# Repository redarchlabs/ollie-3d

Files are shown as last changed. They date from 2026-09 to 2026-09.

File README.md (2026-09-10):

# Build a Reachy robot — start here

Six teams, six robots. Each team builds a complete **Reachy Mini–style robot**: a head that
nods, tilts and turns on six motors, two springy antennae, two arms, a body that turns on a
printed base, a phone for a face, and a Raspberry Pi for a brain. Then you make it yours: its
own name, its own voice, and if you like, its own head designed in Blender.

They are copies of **Ollie**. Everything in this book has been built and broken once already,
and the notes are what that taught.

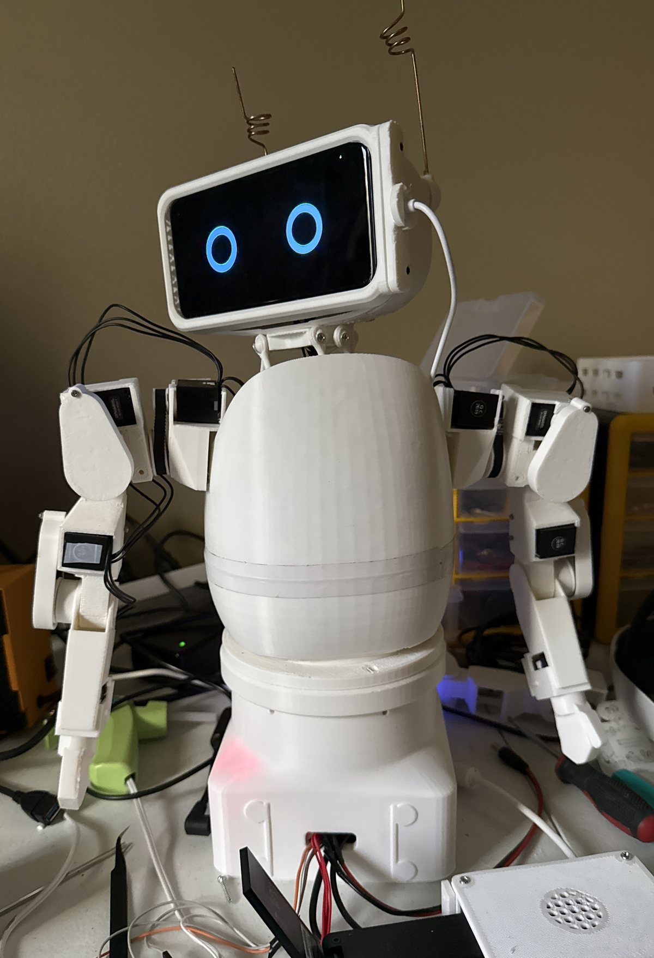
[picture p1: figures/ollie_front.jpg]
Ollie, the robot these are copies of


*Ollie: the phone face in the head, the wire antennae, both arms fixed to the top of the body,
the base that turns, and the Raspberry Pi in its white case beside the base.*

| Read this | When |
|---|---|
| **This page** | Day one: what you're building, the six stages, teams, safety |
| [Stage 1 — Print](1_PRINT.md) | Every printed part, test prints first |
| [Stage 2 — Motor IDs](2_MOTORS.md) | Set up the Pi, give all 17 motors their own ID |
| [Stage 3 — Assembly](3_ASSEMBLY.md) | Put the robot together, with the Pi beside you |
| [Stage 4 — Software](4_SOFTWARE.md) | Name, calibration, arms, autostart, the phone face |
| [Stage 5 — Testing](5_TESTING.md) | The acceptance test, the Code Lab (Blockly and JavaScript), VR control |
| [Stage 6 — Make it yours](6_CUSTOMIZE.md) | Optional: a different phone, voice and eyes, your own head in [Blender](BLENDER.md) |
| [Appendix A — Shopping list](PARTS.md) | What to buy, per robot and for six |
| [Appendix B — Mentor notes](MENTOR_SETUP.md) | Mentors: the kit, SD cards, the network, the power wiring |

---

## What you are building

| Part of the robot | What it is | Motors |
|---|---|---|
| **Head** | A 6-motor *Stewart platform*: six motor arms push six rods that hold up the head. Moving them together makes it nod, tilt, turn and bob | 6 × XL330-M288 (IDs 4–9) |
| **Antennae** | Two bent-wire antennae on the back of the head — the robot's main way to show emotion | 2 × XL330-M077 (IDs 1–2) |
| **Arms** | Two 4-joint printed arms driven by belts: shoulder pitch, shoulder roll, elbow, wrist | 8 × XL330-M288 (right 14–17, left 18–21) |
| **Body** | The "egg" that holds the head motors. The arms screw to the top of it | — |
| **Base** | A printed plinth with a bearing on top; the whole robot turns on it | 1 × XC330-M288 (ID 3) |
| **Face** | A Samsung Galaxy S10 behind the face plate. Its screen is the eyes, its speaker is the voice. A cable keeps it charged | — |
| **Brain** | A Raspberry Pi 5 beside the base. It runs the robot's software and talks to the motors through a USB adapter (the **U2D2**) | — |

**Seventeen motors on one cable.** Every motor is daisy-chained on a single bus, and every
motor has an ID number. The ID is how the software knows which motor is which, so setting the
IDs is the first thing you do with the motors (Stage 2).

**The Pi is your workbench computer.** From Stage 2 on, every command in this book is typed on
your robot's own Pi, with a monitor, keyboard and mouse plugged into it. You don't need a
laptop. The only other computer you'll use is for Blender, if you design a head in Stage 6.

### The six stages

| Stage | What | Who | You're done when |
|---|---|---|---|
| **1 · Print** | Test prints, then every part | Print lead | Every part is printed, checked and labelled |
| **2 · Motor IDs** | Set up the Pi; give each motor its ID | Motors lead + software lead + mentor | A scan finds all 17 motors |
| **3 · Assembly** | Head, antennae, face, arms, base, power | Mechanical lead + motors lead + mentor | The robot is built and its head's "level" is recorded |
| **4 · Software** | Name, calibration, arms, autostart, phone | Software lead + mentor | The robot starts by itself, calibrated |
| **5 · Testing** | Acceptance test, Code Lab, VR | Whole team | Every box on the checklist is ticked |
| **6 · Make it yours** | Optional: phone, voice, eyes, your own head | Designer + everyone | Whenever you like |

Every stage ends in a **✅ checkpoint**. Don't start the next stage until your robot passes it,
and don't start a stage at all until the pilot robot (R1) has passed it. Where a step says
**mentor**, a mentor is at the table for it.

---

## How six teams build six robots

**Every robot has a number, R1 to R6, for its whole life.** Put it on everything: printed parts
(pencil or marker on a hidden face), motors (painter's tape), cables, the SD card, the phone,
the USB stick, the parts bin. Six robots' worth of identical parts on one table is how a
calibrated part ends up in the wrong robot.

**R1 is the pilot robot.** One team runs each stage a few days ahead of everyone else. The other
five start a stage only after R1 has passed its checkpoint. A problem gets found once, not six
times. The same goes for printing: print one of anything new, check it, then print five more.

**Parts that belong to one robot never move to another.** Motors (their IDs and positions are
recorded), rods, motor arms, the calibration file and the phone all get matched to one robot.
Swapping a calibrated part is how the robot on the next table starts moving wrong.

### Roles on a team (4–5 people)

| Role | Owns |
|---|---|
| **Print lead** | The team's print queue, slicer settings, labelling printed parts |
| **Motors & wiring lead** | Motor IDs, cables, the bus, strain relief, the power checks |
| **Mechanical lead** | Rods, motor arms, the head and neck, the arms and belts, the base |
| **Software lead** | The Pi, the phone, the robot's name and voice (with the mentor) |
| **Designer** | Optional: the robot's own head in Blender (everyone can help) |

Everyone owns safety.

---

## Safety — non-negotiable

1. **The motors are 5-volt parts.** The robot's power brick is 12 V, and a converter turns that
   into 5 V for the motors. 12 V on the motor bus destroys **every motor at once**. Only a
   mentor wires or changes the power parts, and the 5 V is measured with a meter before any
   motor is connected.
2. **Power off before you plug or unplug any motor cable.** Hot-plugging is how a motor gets a
   wrong ID or drops off the bus.
3. **Keep fingers out of the neck and the belts while the motors are powered.** Six motor arms
   and six rods make a pinch point, and so does every belt. Before you move the head or an arm
   by hand, it must be *limp* (torque off).
4. **An arm falls when it goes limp.** Hold it, or make sure nothing is under it, before you
   switch the motors off or press PANIC.
5. **Soldering only with a mentor present.** Eye protection, ventilation, iron in its stand.
6. **Hot water for the ball joints (80–90 °C)** — tongs or gloves, mentor present.
7. **Phones:** never put a phone with a swollen battery into the head. The phone charges inside
   the head, so check its back is still flat every time the head is opened.
8. **Printers:** don't touch the nozzle or the bed. PETG needs ventilation.
9. **VR:** the person in the headset can't see the real robot. Someone else always watches the
   robot, with a hand near the power switch.
10. **Children will touch this robot.** Nothing sharp: round every point and edge, including
    the ends of the antenna wire.

---

## Day one

1. **Form six teams**, give each a robot number (R1 = the pilot team) and assign roles.
2. **Safety briefing** — the list above, out loud.
3. **Start printing the test pieces** ([Stage 1](1_PRINT.md)). They answer "will it fit?"
   before anyone commits a ten-hour print. Also start the long, safe prints: `body_top`,
   `body_down`, `head_back`, `base_body`.
4. **Inventory what has arrived** against the [shopping list](PARTS.md). Label boxes R1–R6.
5. **Software leads:** set up your Pi ([Stage 2, step 1](2_MOTORS.md)). It can happen while the
   printers run.
6. **Designers:** if your team wants its own head, install Blender and sketch the character on
   paper first ([Blender](BLENDER.md)). Design runs alongside the build.

## Where the files are

Everything to print, and this book, is in the **ollie-3d** repository. Your team also gets a
**USB stick** from the mentor with the same files plus the robot software:

| Folder | What's in it | Where |
|---|---|---|
| `print/` | Every part for one robot, grouped in printing order. **All millimetres — print at 100 %.** `PRINT_LIST.csv` says how many of each and how to lay it on the bed | ollie-3d and the USB stick |
| `blender/` | The Blender starter file and its check script (Stage 6) | ollie-3d and the USB stick |
| `Reachy-Student-Build-Book.pdf` | This book, ready to print | ollie-3d and the USB stick |
| `software/` | `reachy-software.tar.gz` — the robot software, installed onto the Pi in Stage 2 | USB stick only |

Keep the stick: it's also where your robot's calibration file is backed up.

**Credits.** The stock Reachy Mini parts — the head back, crown cover, neck and Stewart
plates, antenna parts and body shells — are Pollen Robotics' designs, converted here to
millimetres. Everything else was designed for Ollie.

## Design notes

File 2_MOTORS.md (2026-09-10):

# Stage 2 — Motor IDs

Every DYNAMIXEL motor leaves the factory as **ID 1 at 57600 baud**. Seventeen motors all
answering to "1" on one cable just talk over each other, so each motor gets its own ID
**before** they are chained together — one motor at a time, with nothing mechanical attached.
The tool that does it runs on your robot's Pi, so the Pi is set up first.

---

## 1. Set up the Pi — your workbench computer

*Software lead, with the mentor. This can happen on day one while Stage 1 prints.*

You need: the Raspberry Pi 5 and its **official 27 W power supply**, the Active Cooler, the SD
card the mentor prepared for your robot, a monitor and a micro-HDMI cable, a USB keyboard and
mouse, your team's USB stick, and the school wifi (the install downloads packages).

1. Press the **Active Cooler** onto the Pi (its two push-pins go into the holes beside the
   processor) and plug its fan lead into the socket marked FAN.
2. SD card in, then monitor (the HDMI port nearest the power socket), keyboard and mouse, and
   power last. The Pi starts to the desktop.
3. Connect to the wifi from the network icon at the top right, if the mentor hasn't already.
4. Plug in the USB stick. In the file manager, copy `software/reachy-software.tar.gz` from the
   stick into your **home folder**.
5. Open a **Terminal** (the black icon on the top bar) and install the software:
   ```bash
   tar -xzf reachy-software.tar.gz
   cd ~/reachy
   bash scripts/provision_pi.sh
   ```
   It takes several minutes and ends with **Done**. It installs the robot software, the motor
   tools, and the permission to use the motor adapter.
6. **Restart the Pi** (`sudo reboot`). That permission only takes effect after a restart.

**From here on, every command in this book is typed in a Terminal on the Pi, starting in the
`reachy` folder.** A new Terminal starts in your home folder, so type `cd ~/reachy` first.

---

## 2. Motor power on the bench (mentor)

The motors take **5 V** from the **U2D2 Power Hub**. On this robot the Power Hub is fed by a
converter that turns the 12 V power brick into 5 V ([Appendix B](MENTOR_SETUP.md) says how the
mentor wires it).

1. **Mentor:** with no motor plugged in, switch on and measure the Power Hub's input with a meter.
   It must read **about 5.0 V** (4.9–5.1). If it reads 12, stop: something is wired wrong, and 12 V
   destroys every motor it reaches.
2. Switch the Power Hub **off**. Plug the U2D2 into one of the Pi's USB ports, and connect the
   U2D2 to the Power Hub with the short 3-pin cable.

---

## 3. The ID map — the same on every robot

| ID | Motor | Model number the scripts print | Where it goes |
|---:|---|---:|---|
| 1 | XL330-**M077** | 1190 | Left antenna (the robot's own left) |
| 2 | XL330-**M077** | 1190 | Right antenna |
| 3 | **XC330**-M288 (metal case) | 1240 | Body turn, in the base |
| 4–9 | XL330-**M288** | 1200 | The six head motors |
| 14 | XL330-M288 | 1200 | **Right** arm — shoulder pitch (in the shoulder housing) |
| 15 | XL330-M288 | 1200 | **Right** arm — shoulder roll (on the fork, above the shoulder) |
| 16 | XL330-M288 | 1200 | **Right** arm — elbow (lying flat in the upper arm) |
| 17 | XL330-M288 | 1200 | **Right** arm — wrist (in the forearm) |
| 18–21 | XL330-M288 | 1200 | **Left** arm — the same order: pitch, roll, elbow, wrist |

All seventeen run at **1 Mbps** (1 000 000 baud). IDs 10–13 are not used. The software expects
exactly this map.

**The arm order matters.** The software reads the first ID of each arm as the shoulder pitch,
the next as the roll, and so on. On Ollie two shoulder motors went in the wrong places, and the
pitch slider moved the roll joint. Labelling every motor with its job now is what prevents that.

The head and the arms use the **same** motor, the XL330-M288. The two antenna motors (M077) look
identical but are weaker and faster, and the body-turn motor is the one with the metal case.
Check the model number the script prints every time.

---

## 4. Give each motor its ID

1. **Power Hub off.** Plug **one** motor into the Power Hub. Switch on — the motor's LED
   blinks once.
2. Give it its ID and the fast baud rate. For a head motor that will be ID 4:
   ```bash
   cd ~/reachy
   .venv/bin/python scripts/set_id.py --new-id 4 --new-baud 1000000
   ```
   The script refuses if it sees more than one motor, which is the point. It prints the motor's
   model number — check it against the table.
3. **Power off.** Stick a tape label on the motor with robot, ID and job: `R3 · 4 · head`,
   `R3 · 14 · R shoulder pitch`, `R3 · 21 · L wrist`. Unplug it.
4. Repeat for all seventeen: the two **M077** motors (1190) get IDs 1 and 2, the **XC330**
   (1240) gets ID 3, six M288 get 4–9, and eight M288 get 14–21.

## 5. All together, and a health check

5. Chain all seventeen together in any order (power off while you plug), switch on, and scan:
   ```bash
   .venv/bin/python scripts/scan_dynamixel.py
   ```
   You should see **exactly seventeen** motors at 1000000: 1–2 = XL330-M077, 3 = XC330-M288,
   4–9 and 14–21 = XL330-M288. **Count them.** Two motors accidentally given the same ID look
   exactly like one working motor, and nothing else will tell you.
6. **Does every motor actually reach where it's told?**
   ```bash
   .venv/bin/python scripts/nudge_diag.py --ids 1,2,3,4,5,6,7,8,9,14,15,16,17,18,19,20,21
   .venv/bin/python scripts/motor_status.py
   ```
   `nudge_diag` moves each motor a few degrees each way **and reads it back**. A motor whose
   position doesn't change while it draws only a **little** current has a broken gear — the motor
   spins but the output doesn't; Ollie had one straight out of the box. (A **lot** of current and
   no movement means something is blocking it.) `motor_status` should show **no hardware
   error**, about **5 V**, and room temperature on every motor.

### ✅ Checkpoint 2

- [ ] The Pi starts to the desktop, and `cd ~/reachy` works in a Terminal
- [ ] 5 V measured at the Power Hub before any motor was connected
- [ ] The scan shows exactly 17 motors — 1–9 and 14–21 — all at 1000000, the right model on each ID
- [ ] `nudge_diag` shows every motor reaching its targets in both directions
- [ ] Every motor labelled with robot number, ID and job

**If a motor won't show up:** power the motors off and on (a motor that stalled can go silent
until its power is cycled), reseat its cable, try it alone, try
`scan_dynamixel.py --all-bauds`. If its LED lights but it never answers, check the cable is in a
3-pin **TTL** port on the hub. Trust the ID the scan reports over the sticker — stickers get
shuffled.

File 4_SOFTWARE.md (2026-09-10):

# Stage 4 — Software installation

The robot software went onto the Pi in Stage 2. This stage turns it into **your** robot: its
name and settings, a first start, the head's limits and the arms' zeros, starting by itself,
and the phone face. Everything is done on the Pi, with its monitor and keyboard.

| Step | What | Who |
|---|---|---|
| [1](#1-name-and-settings) | The robot's name and settings | Software lead |
| [2](#2-first-start) | First start | Software lead + mentor |
| [3](#3-the-heads-limits-by-hand-posing) | The head's limits, by hand-posing | Mentor + two students |
| [4](#4-the-arms) | The arms: zeros, directions, test | Mechanical lead + mentor |
| [5](#5-start-by-itself) | Start by itself | Software lead |
| [6](#6-the-phone-face) | The phone face | Software lead |

> **One program on the motors at a time.** The robot software owns the motors while it runs.
> If a motor goes limp under it, it switches it back on and drives it home — even if someone is
> holding the head. Stop the software before running **any** motor script (Ctrl-C in its
> Terminal now; after step 5, `sudo systemctl stop reachy`).

---

## 1. Name and settings

Give the robot a **name** — the team's choice, short, easy to say, and **not like any other
robot's** (not "Ollie", and not two names that rhyme). The name is what the robot answers to,
and six robots with similar names means one call wakes six.

Open the settings file:

```bash
cd ~/reachy
nano .env
```

1. Find the line `WAKE_WORD=Ollie` (**Ctrl-W**, type `WAKE_WORD`, **Enter**) and change `Ollie`
   to your robot's name: `WAKE_WORD=Nova`.
2. Go to the very bottom of the file (**Ctrl-End**, or hold the down arrow) and add this line,
   which makes the voice come out of the phone in the head:
   ```
   SPEAK=face
   ```
3. **Ctrl-O**, **Enter** to save, **Ctrl-X** to exit. Leave everything else as it is.

## 2. First start

1. Check the calibration file one more time: `.venv/bin/python -m scripts.calibrate show` must
   say **`(loaded)`** and show your numbers.
2. Start the robot software by hand:
   ```bash
   ./run.sh
   ```
   The head rises to level and holds. **Keep a hand near the Power Hub's switch** the first
   time.
3. Open the web browser on the Pi and go to **`http://localhost:8080`** — the robot's
   **console**. It shows your robot and has buttons for its gestures, head poses and voice.
4. Go to **`http://localhost:8080/health`**. It should show `"backend": "dynamixel"`, and
   inside `"backend_health"`: `"motors"` listing 1–9, and `"calibrated": true`.
5. **Ctrl-C** in the Terminal stops the robot.

## 3. The head's limits, by hand-posing

*Mentor, with one student supporting the head and one at the keyboard.*

The robot knows where "level" is. Now it learns how far the head can go in each direction. The
capture tool needs the motors to itself, so the robot software must be stopped (Ctrl-C).

```bash
cd ~/reachy
.venv/bin/python -m scripts.calibrate show
.venv/bin/python -m scripts.calibrate capture pitch down 25
```

The head goes to level, then limp. Pose it to that limit, press **Enter**, and it saves the
motor positions and goes back to level. Do all eight:

| Command | Pose it to |
|---|---|
| `capture pitch down 25` / `capture pitch up -25` | chin down / chin up, as far as it goes comfortably |
| `capture roll right 20` / `capture roll left -20` | tilt to the robot's right / left |
| `capture yaw right 25` / `capture yaw left -25` | turn to the robot's right / left |
| `capture z up 12` / `capture z down -12` | lift the whole head straight up / lower it straight down |

⚠️ **Support the head at the chin *and* the crown, and rotate it — don't push it.** A hand on
the chin pushes the whole head down while it tips, and that slide gets recorded as part of the
nod: on Ollie the first nod came out as a forward head-thrust. The next command strips the slide
back out, using the two `z` captures as the reference. Keep the raw file first:

```bash
cp data/motor_calibration.json data/motor_calibration.raw.json
python3 scripts/clean_calibration.py
python3 scripts/clean_calibration.py --write data/cleaned.json
mv data/cleaned.json data/motor_calibration.json
.venv/bin/python -m scripts.calibrate show
```

The first `clean_calibration` line only reports; the second writes the cleaned file. `show`
must still say `(loaded)`. Copy **both** `motor_calibration.json` and
`motor_calibration.raw.json` onto the USB stick — the raw one is how the cleaning can be redone.

Now check the directions: start the robot (`./run.sh`) and on the console press **Look R**
(under *Head pose*). The head must turn to the robot's **own** right. Then drag the **Head roll**
slider (on the *Manual controls* card) to the right: the head must tilt to its own right. If one
is mirrored, the two captures for that axis were swapped — capture them again the other way
round.

## 4. The arms

The arms have no "level" to record. Each joint's **zero** is captured with the arm hanging
straight down, after it's built, and that's the reference every angle is measured from.

*The arm goes limp when you're not driving it, and a limp arm falls. Keep hands and faces clear
of it, and keep the mouse near the **PANIC** button. **Watch the first move of every joint** with
a hand ready on PANIC: these arms have never been zeroed on this robot before, and a joint that
has its sums wrong can try to go a long way.*

1. Start the robot (`./run.sh`) and open **`http://localhost:8080/limbs`** on the Pi.
2. Pick the **right** side. Press **🔍 Find motors** — it finds the arm's four motors and moves
   nothing. (The title at the top of the page always says "right arm"; trust the side buttons.)
3. Let the arm hang **at rest**: straight down, the forearm in line with the upper arm, the palm
   facing the body. Hold it still and press **⦿ Capture zero**.
4. Tick **Drive the real arm**. The arm switches on and holds exactly where it is.
5. **Check each joint's direction.** Move each slider a little way and watch the real arm:
   shoulder pitch should swing the arm forward, shoulder roll should lift it out to the side,
   the elbow should bend the forearm forward, and the wrist should turn the hand. If a joint goes
   the wrong way, press its **⇄** button — that's safe while the arm is live.

   **If a slider moves the wrong joint** — the pitch slider moves the roll joint, say — two motors
   are in each other's places, and ⇄ can't fix that. Untick **Drive the real arm**, pick the
   right motor from that joint's **id** list (picking one another joint holds swaps the two), press
   **🔍 Find motors**, and check the directions again.
6. Press **🎯 Test live robot**. It moves each joint a little, one at a time, and checks that it
   really moved. If it stops and lets the arm go limp, it found a joint that didn't move — a
   slipped belt or a stuck joint. Fix that before going on.
7. Untick **Drive the real arm**, pick the **left** side, and do steps 2–6 again.
8. **Make the arms come up with the robot:** stop the robot (Ctrl-C), open `.env` in `nano`,
   find `ARM_START=off` and change it to:
   ```
   ARM_START=both
   ```

An arm goes limp after about 15 seconds with no command and switches back on by itself at the
next one. That's normal, and it's what stops a motor holding a pose until it overheats.

## 5. Start by itself

When the head and both arms are calibrated, make the robot start whenever the Pi does:

```bash
cd ~/reachy
bash scripts/provision_pi.sh --service
sudo systemctl restart reachy
```

Restart the Pi (`sudo reboot`). About 15 seconds after the desktop appears, the head goes level
on its own and `http://localhost:8080` shows the console.

From now on **the robot software owns the motors whenever the Pi is on.** Before any motor
script:

```bash
sudo systemctl stop reachy
pgrep -af 'app\.main|app\.serve'
```

The second line must print **nothing** (if it prints anything, the software is still running).
Run your script, then `sudo systemctl start reachy` afterwards.

## 6. The phone face

The phone is set up **before** it goes into the head — once it's inside, its settings are hard to
reach.

1. **Check the battery:** the back glass must sit flat. A swollen phone never goes in a head.
2. Turn on **Stay awake**: *Settings → About phone → Software information*, tap **Build number**
   seven times to unlock Developer options, then *Settings → Developer options → Stay awake*.
3. Turn **auto-brightness off** and set the brightness by hand. Set the screen timeout to the
   maximum.
4. Put the phone on **the same wifi as the Pi**.
5. On the Pi, open **`http://localhost:8080/pair?audio=1`**. It shows a QR code. Scan it with the
   phone's camera, open the page, and in Chrome's menu (⋮) choose **Add to Home screen**. (The
   `?audio=1` matters: plain `/pair` makes the phone the eyes only, with no voice.)
6. Open the face from the new home-screen icon. **Tap it once** — phones stay silent until
   they're tapped. The eyes are **amber** until that tap, then they turn to normal.
7. Touch the face and press **🔊 Test audio**. It should speak.
8. **Into the head:** slide the phone into the face plate, **screen forward, charging port at the
   service-cap end**. The last few millimetres take a firm push — that's the plate's pads
   pressing the phone onto the front lip, and it's what stops the rattle. Plug in the charging
   cable, lead it out past the cap the way Ollie's is, and fit the service cap: tongue in,
   2 × M2 × 10 self-tapping. Don't pinch the cable.

Whenever the phone's page reloads — after the robot restarts, say — the eyes go amber again and
it needs one tap before it can make a sound.

**Back up:** copy `data/motor_calibration.json`, `data/motor_calibration.raw.json` and `.env`
onto the USB stick. (`.env` starts with a dot, so the file manager hides it — press **Ctrl-H** to
show hidden files.)

### ✅ Checkpoint 4

- [ ] `WAKE_WORD` in `.env` is set to the robot's own name
- [ ] After a restart it comes up by itself: the head goes level and holds, `/health` shows
      `"backend": "dynamixel"` and, inside `"backend_health"`, motors 1–9 and `"calibrated": true`
- [ ] **Look R** turns the head to the robot's own right, and **Head roll** tilts it the right way
- [ ] Both arms passed **🎯 Test live robot**, and `/health` shows both arms `"zeroed": true`
- [ ] The phone shows the eyes, speaks, and is charging inside the head
- [ ] The calibration files and `.env` are backed up on the USB stick

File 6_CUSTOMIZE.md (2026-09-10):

# Stage 6 — Make it yours (optional)

Your robot works. Everything in this chapter is optional, and none of it should be started until
your robot has passed Stage 5 — a customisation is much easier to trust on a robot you already
know works.

| Customisation | Effort | Who |
|---|---|---|
| [Name, voice and eyes](#name-voice-and-eyes) | Minutes, on the console | Anyone |
| [Your own head, designed in Blender](BLENDER.md) | Days — design, check, print | Designer + team |
| [A different phone for the face](#a-different-phone) | A reprinted face plate | Mentor + team |

---

## Name, voice and eyes

- **Name.** `WAKE_WORD` in `.env` (Stage 4). Change it with `nano .env`, then
  `sudo systemctl restart reachy`.
- **Voice.** The console's **🗣️ Speech & voice** card picks the robot's voice from a list of
  characters, and has sliders for how fast it talks. The robot remembers your choice after a
  restart.
- **Eyes.** Touch the phone's face and a bar rises from the bottom: **◀ / ▶** step through 36
  eye styles, named as you go. Pick one before the head is closed up.
- **A more natural voice (mentor).** Out of the box the Pi speaks with *espeak*, which sounds
  properly robotic. For smoother voices, on the Pi:
  ```bash
  cd ~/reachy
  bash scripts/fetch_voices.sh
  bash scripts/provision_pi.sh --voices
  sudo systemctl restart reachy
  ```
  It needs internet and about 500 MB of space.

## Your own head

The next chapter, [Designing your robot's head in Blender](BLENDER.md), is the big one. You
start from the standard head and add ears, horns, a crest, a visor or your robot's name, and a
script checks your design against every rule the robot needs before it exports the file you
print. Blender runs on a Windows, Mac or Linux computer — use a school computer for it, not the
robot's Pi.

---

## A different phone

The face plate is made for a **Samsung Galaxy S10** (model SM-G973) to a fraction of a
millimetre: 149.9 × 70.4 × 7.8 mm, 157 g. The plain S10 — not the S10e, S10+ or S10 5G. A
different phone means a **new face plate**, made by the mentor from the phone's measurements.

**A phone is a good candidate if:**

- it's **Android with Chrome**. An iPhone can show the face, but it can't reopen the page by
  itself after a power cut, and a sealed head needs that;
- it's **close to the S10's size**. The S10 is already as wide as the head (150 mm), so a longer
  phone sticks out at the sides;
- it's **no heavier than 157 g**. Six small motors hold the head up, and the phone is most of its
  weight;
- it has an **OLED screen** if possible, so the black around the eyes is truly black;
- its battery is **not swollen** — the back sits flat.

**Making the new plate:**

1. **Measure the phone** with calipers, to 0.1 mm: length, height, thickness. Weigh it. Note
   where its rear camera bump is.
2. **Mentor:** put the three measurements into `PHONE_W`, `PHONE_H` and `PHONE_T` at the top of
   `hardware/s10-face/generate_s10_face.py` in the robot's main repository, regenerate the plate
   and cap, and run the fit check (`verify_s10_face.py`). The S10's camera relief (`CAM`) and screen window (`WIN_W`, `WIN_H`)
   are there too. The file's README says how.
3. **Print a test plate first**, exactly like the face-plate test print in Stage 1: the phone
   slides in with a firm push at the end, the cap screws shut, and nothing rattles.
4. **Set the eyes' size** on the new phone: touch the face, press **⚙**, hold a ruler against the
   blue bar and adjust it until it is **exactly 50 mm**. The face then draws its eyes at the right
   size on that screen.
5. Set the new phone up as in Stage 4, step 6 — Stay awake, brightness, pairing, one tap.

⚠️ A heavier phone changes how the head moves. After fitting one, re-run the acceptance test in
Stage 5, and if the head sags or struggles to reach its limits, go back to the S10.

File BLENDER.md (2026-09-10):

# Designing your robot's head in Blender

Every robot gets the same neck, body and base — they hold motors, a phone and a computer, and
their shapes are measured to a fraction of a millimetre. **The head is yours.** You start from
the standard head and add to it: ears, horns, a crest, a visor, a badge, your robot's name
engraved on its side. A script checks your design against every rule below and exports the
file you print.

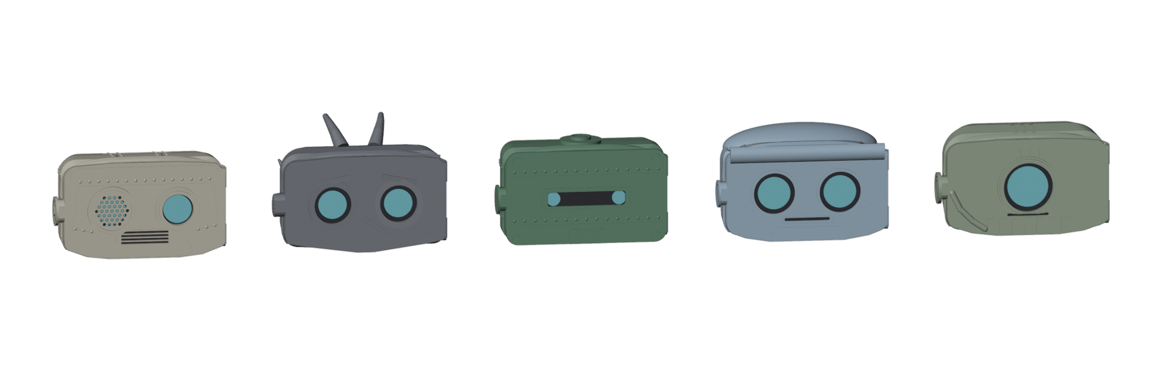
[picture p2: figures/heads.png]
The five character heads designed for the original robot


*The character heads designed for the original robot — tinhead, vex, boiler, pip and iris.
Every one fits the same neck and the same phone. Yours will too.*

---

## 1. Set up

1. Install **Blender 4.5 LTS** from [blender.org](https://www.blender.org/download/) (any
   version from 4.2 up works). It's free and runs on Windows, Mac and Linux.
2. Optional but useful: the **3D Print Toolbox** add-on. *Edit ▸ Preferences ▸ Get
   Extensions*, search "3D Print Toolbox", **Install**. It checks wall thickness and overhangs.
3. Get the starter file, `reachy_head_starter.blend`, from the `blender/` folder — in the
   ollie-3d repository, or on your team's USB stick.
4. Open it, then straight away **File ▸ Save As** into your own folder, named after your robot
   (`R3-nova.blend`). Never work in the original.

## 2. What's in the starter file

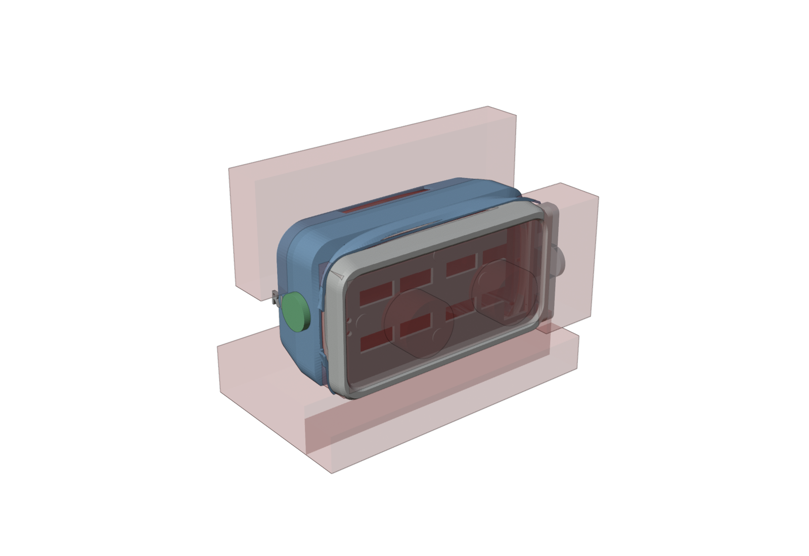
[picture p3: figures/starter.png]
The starter file


| Colour | What it is | Can you change it? |
|---|---|---|
| **Blue** | The back shell — the part that slides over the back of the head | No — it's locked. You add to it |
| **White** | The face plate that holds the phone | No — locked. You can add small details to it |
| **Grey, see-through** | Parts inside and underneath: the stock head back, the crown cover, the body, the service cap, the phone | No — they're there so you can see what you're designing around |
| **Red, see-through** | **Keep-out zones** — nothing you make may go in them | No |
| **Green** (hidden) | Two examples: an ear disc and an engraved label | Copy them, move them, delete them |

The Outliner (top right) has two collections that are yours:

- **MY ADD-ONS** — every object you want to *add* to the head goes here.
- **MY CUTS** — every object you want to *carve out* of the head (engraved letters, grooves)
  goes here.

Anything outside those two collections is ignored when you export. To move an object into one,
select it, press **M** and pick the collection.

**Units are millimetres.** The face looks toward **−Y**. Handy views: **Numpad 1** front,
**Ctrl + Numpad 1** back, **Numpad 3** side, **Numpad 7** top. No numpad? *Edit ▸ Preferences ▸
Input ▸ Emulate Numpad*, then use the number row.

## 3. The rules

The check script tests all of these for you. Knowing them first saves you redesigns.

| Rule | Why |
|---|---|
| **Sink every add-on about 1 mm into the surface.** | If it only touches the surface it prints as a separate piece and falls off |
| **Stay out of the red zones.** | Each one is something your design would break: the inside of the head, the phone's pocket, the eyes, the phone's glass, the service cap (the phone slides out there to charge), below the head (the neck and body), and the **antenna band** across the top and back, where the antennae swing |
| **Back shell: 65 g or less in total.** The plain shell weighs about 45 g, so you have about 20 g to add. **Face plate: 15 g or less added.** | Six small motors hold up the head and a 157 g phone. Weight on the head is the one thing they can't argue with |
| **Size:** no more than 88 mm out to each side, 75 mm up, 52 mm back, and face details no more than 5 mm proud of the face | Bigger heads hit things when they turn, and cost motor strength |
| **Nothing below the head.** | The head nods, tilts and turns right down to the body. The check swings your add-ons through every pose and fails anything that gets closer to the body than the standard head already does |
| **Engravings no deeper than 0.8 mm.** | The shell wall is only 1.6 mm thick |
| **Don't cover the phone's camera** if your design covers part of the screen. | The camera, near one end of the screen, is how the robot sees who is talking. The check can't see it — hold your print up to the phone and look |
| **Nothing thinner than 1.2 mm. Round every point and edge** — at least 1 mm radius on tips. | Thin bits snap. **Children will touch this robot** |
| **Each add-on and cut is its own closed object.** | Open meshes (holes, loose edges) can't be printed. Text objects are fine as they are |
| **Nothing crosses the line where the face meets the back shell.** | They are separate prints. A crest that runs from face to crown is two objects, split at that line |

## 4. Make an add-on

The example **ear disc** shows the pattern. Turn on the green EXAMPLES collection (the eye icon
in the Outliner) to see it.

1. **Add ▸ Mesh ▸ Cylinder** (or Cone, UV Sphere, Cube…).
2. Press **N** for the side panel. Type exact numbers into *Location*, *Rotation*, *Dimensions*.
3. Push it into the surface until about 1 mm is buried. Check it from two views.
4. **M ▸ MY ADD-ONS.**

Shaping tips:

- **Round it** with a *Bevel* modifier (width 1–2 mm, segments 3) — modifiers count; the
  check uses the finished shape.
- **Smooth it** with a *Subdivision Surface* modifier.
- **Horns and fins:** start from a cone, then *Edit Mode* (**Tab**) with proportional editing
  (**O**) to curve it.
- **Sculpting** is fine on **your own** objects. Afterwards add a *Remesh* modifier
  (Voxel, 0.5 mm) so it is a closed solid.
- **Mirror** left and right with a *Mirror* modifier (axis X) — both sides for the price of one.
- **Save weight:** hollow a big add-on with a *Solidify* modifier (thickness 1.6 mm), keeping
  it closed.

## 5. Engrave something

The example **engraved label** shows the pattern.

1. **Add ▸ Text.** **Tab** to edit it, type your robot's name, **Tab** again.
2. In the green **"a"** (Object Data) tab: *Geometry ▸ Extrude* = **1.0 mm** (that makes it
   2 mm deep in total), *Size* = 10–14 mm. Chunky fonts engrave best; letters under 8 mm tall
   are hard to read.
3. Rotate it so its face points out of the surface, and place it so it cuts **0.8 mm** in.
4. **M ▸ MY CUTS.** The check shows cuts as wireframe so they don't hide what they cut.

**Raised letters** are the same object put in **MY ADD-ONS** instead, sunk 0.5–1 mm.

## 6. Check and export

1. Save (**Ctrl + S**).
2. Click the **Scripting** tab at the top. `reachy_check.py` is open in the text editor.
3. At the top of the script, set your robot and design name:
   ```python
   ROBOT = "R3"
   DESIGN = "nova-horns"
   KEEP_ANTENNAE = True    # False only if your robot has no antennae
   ```
4. Press **Run Script** (▶, or **Alt + P**). The report appears in the text editor.

A passing report looks like this:

```
REACHY HEAD CHECK  -  R3 / nova-horns   (antennae kept)

ADD-ONS
  OK    horn_left (shell): closed, attached, clear of every keep-out zone
  OK    horn_right (shell): closed, attached, clear of every keep-out zone

CUTS
  OK    name (shell): closed, attached, clear of every keep-out zone

HEAD MOVEMENT
  OK    Swept 135 head poses: your add-ons never come closer to the body than
        the standard head does (nearest 55.5 mm, at pitch +25, roll +20, ...)

WEIGHT
  OK    back shell: 47.4 g of 65 g
  NOTE  face plate unchanged - print the standard s10_face_plate.stl

RESULT
  PASS - exported:
         .../export/R3_nova-horns_shell.stl
```

**PASS** means your STL files are in the **export** folder beside your `.blend`. **FAIL** means
nothing was exported. Fix each line marked **FIX** and run it again:

| The report says | Do this |
|---|---|
| *reaches inside the head* | Pull it outward. Only ~1 mm should be buried |
| *reaches in where the face plate slots into the shell* | Move it back from the front edge of the shell by a few mm |
| *covers an eye* / *would press on the phone's glass* | Move it off the eye circles; keep masks in front of the face |
| *blocks the service cap* | Keep the service-cap side of the face clear — the side with the small screwed-on cap (+X) |
| *the antennae swing through there* | Move it forward or back out of the band across the crown |
| *doesn't touch* | Sink it about 1 mm into the surface |
| *isn't a closed solid* | *Mesh ▸ Clean Up ▸ Fill Holes*, or 3D Print Toolbox ▸ *Make Manifold* |
| *crosses the line where the face plate meets the back shell* | Split it into two objects, one each side |
| *comes within … mm of the body* | Make the lower part of your design smaller or higher up |
| *… g of 65 g* failing | Make add-ons smaller, or hollow them (Solidify) |

To look at exactly what will be printed, turn on the **RESULT** collection in the Outliner.
For a last check, select `PRINT_shell` and run 3D Print Toolbox ▸ *Check All* — thin walls and
steep overhangs show up there.

## 7. Print it

- **Back shell:** collar-down (the open front edge flat on the bed), PETG, 3 walls, 15 %
  infill, 0.2 mm layers. Tall horns may want a few supports.
- **Face plate with raised details on the front:** print it **face up** (the flat rear band on
  the bed), with supports only inside the phone tunnel. The plain face plate prints face down,
  but raised details would be on the bed.
- **Weigh it** on a kitchen scale. The shell must come in at 65 g or less.
- **Colour:** paint with acrylic over a primer, or change filament at a layer height in the
  slicer (a colour band costs nothing in weight).

The shell slides onto the back of the head and grips by itself. No screws, so you can swap
heads in seconds.

## Going further

Want a completely new silhouette, not add-ons on the standard one? The character heads were
generated from numbers in Python in the robot's main repository
(`hardware/heads/generate_characters.py`, specified in
`hardware/heads/CHARACTER_SPEC.md`), so the fit to the robot is exact. Describe your shape
to your mentor. The mentor can also make a starter file from any of the character shells:

```bash
blender -b --factory-startup -P hardware/heads/blender/make_starter.py -- \
    --shell character_pip_shell --out pip_starter.blend
```

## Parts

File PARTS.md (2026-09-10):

# Appendix A — Shopping list

Everything to **buy**. What to **print** is [Stage 1](1_PRINT.md). Quantities are **per robot**,
with a **×6** column for the whole program. Prices change; confirm each listing before ordering.

---

## Motors — the expensive part

| Part | Per robot | ×6 | Fleet spares | Notes |
|---|---:|---:|---:|---|
| **DYNAMIXEL XL330-M288-T** | 14 | 84 | 6 | 6 for the head, 4 for each arm. One of the original robot's motors arrived with a mis-moulded gear — buy spares |
| **DYNAMIXEL XL330-M077-T** | 2 | 12 | 1 | The antennae — a weaker, faster version. Don't mix them up with the M288 |
| **DYNAMIXEL XC330-M288-T** | 1 | 6 | 1 | The body turn. Metal case, because it turns the whole robot |

All three are 5 V motors on the same 3-pin cable. Each motor comes with one short cable.

## Motor bus and power

| Part | Per robot | ×6 | Notes |
|---|---:|---:|---|
| **ROBOTIS U2D2** | 1 | 6 | The USB adapter between the Pi and the motors |
| **ROBOTIS U2D2 Power Hub Board Set** | 1 | 6 | Where the motors plug in and get their 5 V |
| ROBOTIS Robot Cable-X3P, assorted lengths | 8 | 48 | Longer motor cables for the arms and the run up through the body — the stock ones are short |
| **12 V power brick**, 120 W or more | 1 | 6 | The robot's one plug for the motors and the phone. Ollie's is 160 W |
| **12 V → 5 V step-down converter, 10 A (50 W)** | 1 | 6 | Feeds the Power Hub, i.e. all 17 motors. ⚠️ The motors must only ever see **5 V** |
| 12 V → 5 V USB charger module (USB-A) | 1 | 6 | Charges the phone in the head |
| Fuse holder + 10 A fuses, rocker switch, wire, lever connectors, 2200 µF capacitor | 1 set | 6 | The mentor builds the power wiring from these — see [Appendix B](MENTOR_SETUP.md) |

## Brain — and the workbench

| Part | Per robot | ×6 | Notes |
|---|---:|---:|---|
| **Raspberry Pi 5, 4 GB** | 1 | 6 | Ollie runs on a 2 GB board and it is a real ceiling. 4 GB removes that |
| **Official Raspberry Pi 27 W USB-C power supply** | 1 | 6 | Not a generic 5 V supply — one measured 4.99 V on Ollie and made the Pi crash |
| microSD, 32 GB, high-endurance (Samsung PRO Endurance or SanDisk Max Endurance) | 1 | 6 | +2 spares. Label it with the robot number |
| Raspberry Pi 5 Active Cooler | 1 | 6 | |
| USB stick, 16 GB or more | 1 | 6 | The student kit, and the robot's calibration backups |
| **Monitor with HDMI**, USB keyboard and mouse | 1 set | 6 | The Pi is the workbench computer from Stage 2 on. Any school monitor and keyboard will do; they can be shared once a robot is finished |
| Micro-HDMI to HDMI cable | 1 | 6 | The Pi 5's video ports are micro-HDMI |

## Face

| Part | Per robot | ×6 | Notes |
|---|---:|---:|---|
| **Samsung Galaxy S10 (SM-G973)**, used is fine | 1 | 6 | The plain S10 — **not** the S10e, S10+ or S10 5G. The face plate is sized to this phone to a fraction of a millimetre. Check the screen has no burn-in and the battery isn't swollen. A different phone means a new face plate ([Stage 6](6_CUSTOMIZE.md)) |
| USB-A to USB-C cable, about 1 m, thin | 1 | 6 | From the USB charger in the base, up through the body, to the phone |

## Base and yaw joint

| Part | Per robot | ×6 | Notes |
|---|---:|---:|---|
| **6816-2RS thin-section bearing**, 80 × 100 × 10 mm | 1 | 6 | +1 spare |
| Brass spacer, ⌀6 mm OD × ⌀3.2 mm bore × 20 mm | 4 | 24 | R1 measures one of the body's four ⌀6.64 columns with a pin gauge **before** the fleet order |
| Stick-on rubber feet, ⌀12 mm | 8 | 48 | 4 for the plinth, 4 for the Pi case |

## Antenna wire

| Part | Per robot | ×6 | Notes |
|---|---:|---:|---|
| Stiff wire, brass or steel | about 50 cm | 3 m | Bent by hand into the two antennae. R1 measures the hole in the printed antenna hub and buys wire that's a snug push fit |

## Arms (both arms)

| Part | Per robot | ×6 | Notes |
|---|---:|---:|---|
| **GT2 closed-loop belt, 122 mm (61 teeth), 6 mm wide** | 4 | 24 | Shoulder pitch and shoulder roll, both arms. +1 spare per robot |
| **GT2 closed-loop belt, 140 mm (70 teeth), 6 mm wide** | 2 | 12 | The elbows. +1 spare per robot |

## Screws

The stock Reachy parts use the screws listed in the official
[Reachy Mini assembly guide](https://huggingface.co/spaces/pollen-robotics/Reachy_Mini_Assembly_Guide).
Buy each team an **M2 / M2.5 / M3 assortment** (machine screws, self-tapping screws and nuts)
for those. The custom parts need these specifically.

### Head, face and base

| Screw | Per robot | Where |
|---|---:|---|
| M2 × 5 self-tapping | 24 | Motor arms → motor boss (4 per arm) |
| M3 × 18 + M3 nut | 12 + 12 | Rods: through the ball into the motor arm, and the rod tops into the neck plate. R1 confirms the top-end length |
| M2 × 10–12 self-tapping | 2 | Face service cap |
| M2 × 8 | 4 | Yaw motor → the base's motor bridge |
| M2 × 10 | 4 | Yaw clamp → the yaw motor's boss |
| M3 × 8 countersunk | 3 | Yaw clamp → rotor, from below |
| M3 × 14 thread-forming | 6 | Base cap → plinth, sideways through the drum wall |
| Body clamshell screws, **longer than stock** | 4 | They now reach through the rotor into the body. R1 measures the length |
| M3 × 8–10 | 4 | U2D2 Power Hub Board → its tray |
| M2.5 × 8 | 8 | Pi → tray (4), cover → tray (4) |
| M3 × 16 thread-forming | 4 | Pi case → plinth wall |

### Arms — for both arms

| Screw | Per robot | Where |
|---|---:|---|
| M2 × 5 **countersunk** (90°, DIN 965) | 32 | Boss adapters (4 each × 6) and hand adapters (4 each × 2). Countersunk, not pan head: the seat is a cone |
| M2 × 8 | 6 | The centre screw in each small pulley |
| M2 × 16 | 18 | Big pulleys → their joints, 3 each |
| M2 × 16 **countersunk** | 4 | One per belt cover. Not shorter — the screw crosses the cover's own boss first |
| M2 × 6 | 8 | Pitch and elbow motors, 2 each |
| M2 washer, about 5 mm across | 4 | Under the elbow motors' screws |
| M2 × 20 self-tapping | 4 | Roll motors, 2 each |
| M3 × 12 | 4 | Wrist clamps, 2 each |
| M3 × 10 self-tapping, or a 2.5 mm pin | 2 | Pins each pitch shaft to its fork |
| M3 × 12 + M3 nut | 8 + 8 | Shoulder housings → body shell, 4 each. R1 confirms the length |

## Tools

**Per team:** metric hex keys and small screwdrivers (Phillips #0 and #1, and a small flat blade
for belt tension), digital calipers, a multimeter, a drill with 2.5 mm and 3.2 mm bits, a small
vice (for pressing bushings), a small spirit level (or a phone level app), flush cutters,
needle-nose pliers, a file, zip ties, painter's tape and a marker, a hot-glue gun, a deburring
tool and fine sandpaper.

**Shared:** a kettle and a thermometer (ball joints are swaged in 80–90 °C water), a pin gauge
set or drill bits to measure holes, and a Meta Quest headset for the VR test in Stage 5.

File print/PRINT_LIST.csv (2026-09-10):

group | file | qty per robot | size mm | how to print | done
1-test-prints | eye_hug_test.stl | 1 | 4 x 61 x 28 | Press a ball into each eye; longest stub = most grip
1-test-prints | yaw_clamp.stl | 1 | 86 x 86 x 9 | Print NOSE UP. Check it seats on the XC330 boss
1-test-prints | coupon_joints.stl | 1 | 26 x 84 x 45 | BOTH arm joints, printed the way the arm prints. As loaded, do not rotate. Must turn by hand
1-test-prints | hand_adapter.stl | 1 | 20 x 20 x 13 | Snap test with hand.stl - the hand must click on
1-test-prints | hand.stl | 1 | 33 x 22 x 44 | Snap test with hand_adapter.stl
2-head-and-neck | head_back.stl | 1 | 150 x 70 x 88 | Supports under the openings
2-head-and-neck | head_mic.stl | 1 | 118 x 40 x 9 | Crown cover - easy to forget
2-head-and-neck | s10_face_plate.stl | 1 | 157 x 23 x 94 | Face DOWN, no supports. Galaxy S10 only
2-head-and-neck | s10_face_cap.stl | 1 | 13 x 21 x 76 | Tongue side down
2-head-and-neck | neck_reference.stl | 1 | 103 x 52 x 28 | 20% infill
2-head-and-neck | stewart_main_plate.stl | 1 | 145 x 126 x 39 | 20% infill
2-head-and-neck | stewart_tricap.stl | 1 | 146 x 127 x 43 | 20% infill
2-head-and-neck | rod_v6_eye_rod_122mm.stl | 8 | 4 x 13 x 135 | 6 + 2 spare. 0.15 mm layers, flat, 4 walls, 40%+ infill
2-head-and-neck | balls_production_9.05_x6.stl | 3 | 89 x 9 x 8 | 2 plates + 1 spare. As oriented, 0.10-0.15 mm layers
2-head-and-neck | arm_30mm.stl | 8 | 42 x 16 x 3 | 6 + 2 spare. Flat, 4 walls, 50%+ infill
3-antennae | antenna_body.stl | 2 | 22 x 13 x 22 | One per antenna
3-antennae | antenna_interface.stl | 2 | 17 x 7 x 17 | One per antenna
3-antennae | antenna_holder_l.stl | 1 | 40 x 31 x 46 | 20% infill
3-antennae | antenna_holder_r.stl | 1 | 40 x 31 x 46 | 20% infill
4-body | body_top.stl | 1 | 155 x 155 x 120 | Supports under the openings. Long print. The arms screw to it
4-body | body_down.stl | 1 | 155 x 155 x 52 | Supports under the openings
5-base | base_body.stl | 1 | 148 x 139 x 110 | About ten hours. Upright, no supports, 20%, PETG, bridge detection on
5-base | base_top.stl | 1 | 146 x 146 x 24 | Flat, upright, no supports, 25-30% infill
5-base | yaw_rotor.stl | 1 | 143 x 143 x 25 | Flat, upright, no supports, 25-30% infill
5-base | yaw_clamp.stl | 1 | 86 x 86 x 9 | NOSE UP (skip if the test print passed and is kept)
5-base | u2d2_tray.stl | 1 | 53 x 62 x 9 | No supports
5-base | base_shelf.stl | 1 | 94 x 96 x 46 | Optional. Disc down, legs up
6-pi-case | pi5_tray.stl | 1 | 109 x 76 x 29 | As it loads, no supports, 20%
6-pi-case | pi5_cover.stl | 1 | 105 x 76 x 28 | UPSIDE DOWN - roof flat on the bed
7-arms | arm_printed_left.stl | 1 | 54 x 158 x 97 | Joints printed in place. As loaded, DO NOT ROTATE. Support on build plate only. Never let the slicer merge/repair it
7-arms | arm_printed_right.stl | 1 | 54 x 158 x 97 | The mirror of the left - not the same part. Same rules
7-arms | shoulder_housing.stl | 2 | 50 x 60 x 31 | As loaded, do not rotate. Screws to the body
7-arms | hand.stl | 2 | 33 x 22 x 44 | Serves both arms
7-arms | hand_adapter.stl | 2 | 20 x 20 x 13 | The hand snaps onto it
7-arms | wrist_clamp.stl | 2 | 28 x 26 x 4 | Holds the wrist motor in its cradle
7-arms | boss_adapter.stl | 6 | 8 x 20 x 20 | On its side, as loaded
7-arms | pulley_20t.stl | 6 | 15 x 15 x 8 | One per belted motor
7-arms | pulley_40t_flange.stl | 6 | 28 x 28 x 8 | One per belted joint
7-arms | belt_cover_roll_left.stl | 1 | 35 x 63 x 13 | Flat, no supports
7-arms | belt_cover_roll_right.stl | 1 | 35 x 63 x 13 | Flat, no supports. The mirror of the left
7-arms | belt_cover_elbow.stl | 2 | 75 x 35 x 12 | Flat, no supports. Serves both arms
7-arms | bushing.stl | 4 | 16 x 16 x 5 | Two per shoulder housing
7-arms | shaft_pitch_44mm.stl | 2 | 5 x 44 x 5 | LYING DOWN
7-arms | collar_2mm.stl | 2 | 9 x 9 x 2 | Pitch-shaft shim - print all three sizes, fit one
7-arms | collar_3mm.stl | 2 | 9 x 9 x 3 | Pitch-shaft shim
7-arms | collar_4mm.stl | 2 | 9 x 9 x 4 | Pitch-shaft shim

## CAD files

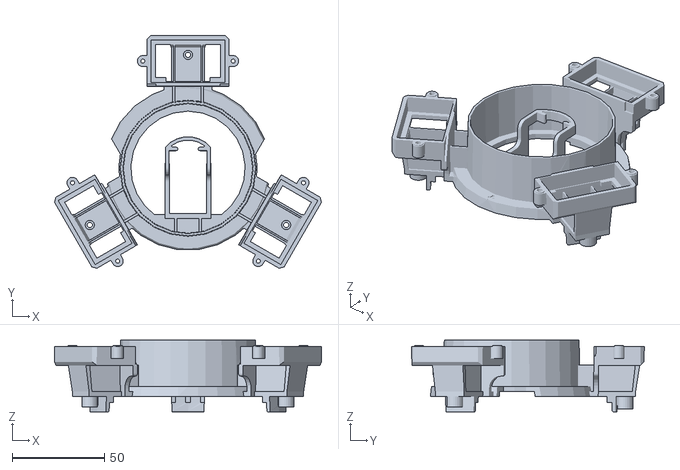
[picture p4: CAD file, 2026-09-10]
print/2-head-and-neck/stewart_main_plate.stl
144.8 x 126.1 x 38.8

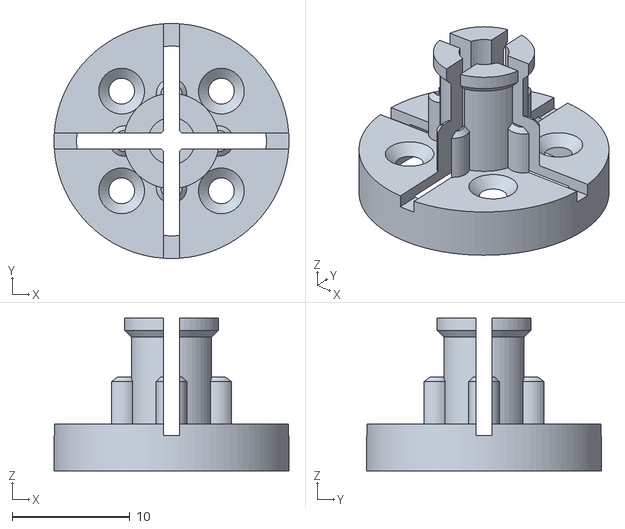
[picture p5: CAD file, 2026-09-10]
print/1-test-prints/hand_adapter.stl
20.0 x 20.0 x 13.0

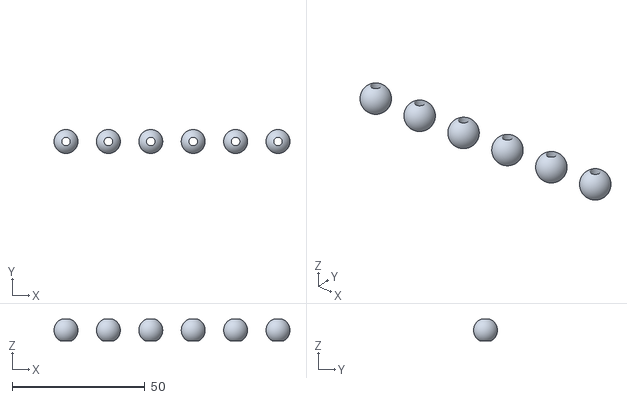
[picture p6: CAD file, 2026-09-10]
print/2-head-and-neck/balls_production_9.05_x6.stl
89.1 x 9.05 x 8.26

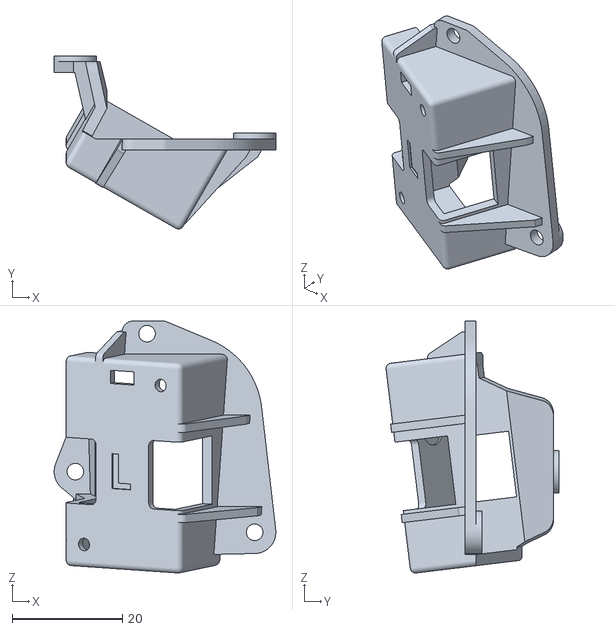
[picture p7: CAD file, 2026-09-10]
print/3-antennae/antenna_holder_l.stl
40.2 x 31.4 x 45.7

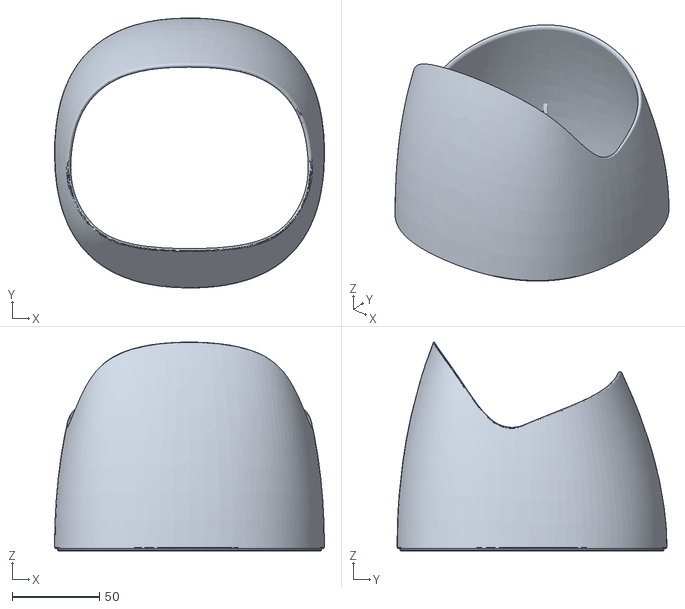
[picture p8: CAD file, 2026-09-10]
print/4-body/body_top.stl
155.0 x 155.0 x 119.8

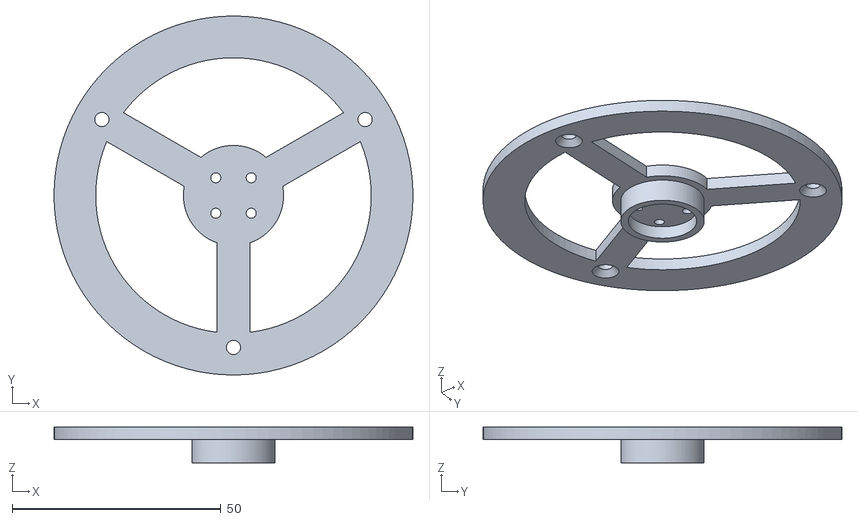
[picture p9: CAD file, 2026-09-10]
print/5-base/yaw_clamp.stl
86.0 x 86.0 x 8.60

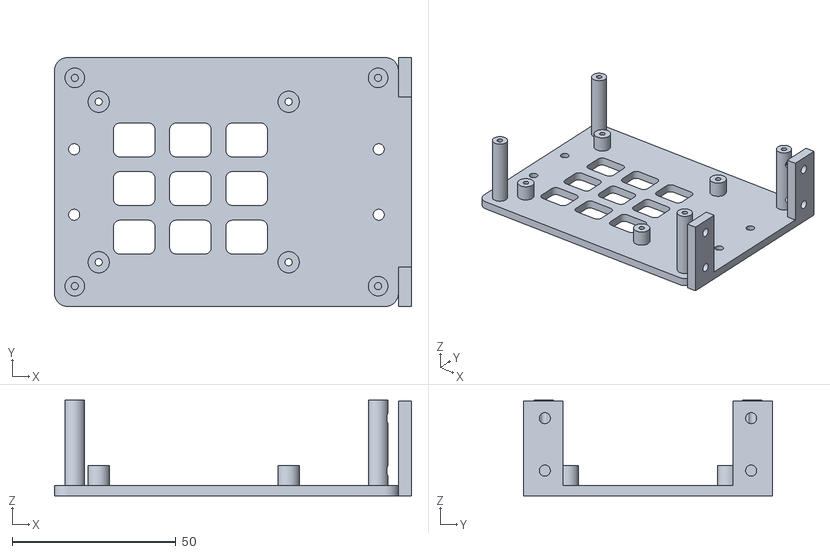
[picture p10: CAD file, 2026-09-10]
print/6-pi-case/pi5_tray.stl
109.0 x 76.0 x 29.2

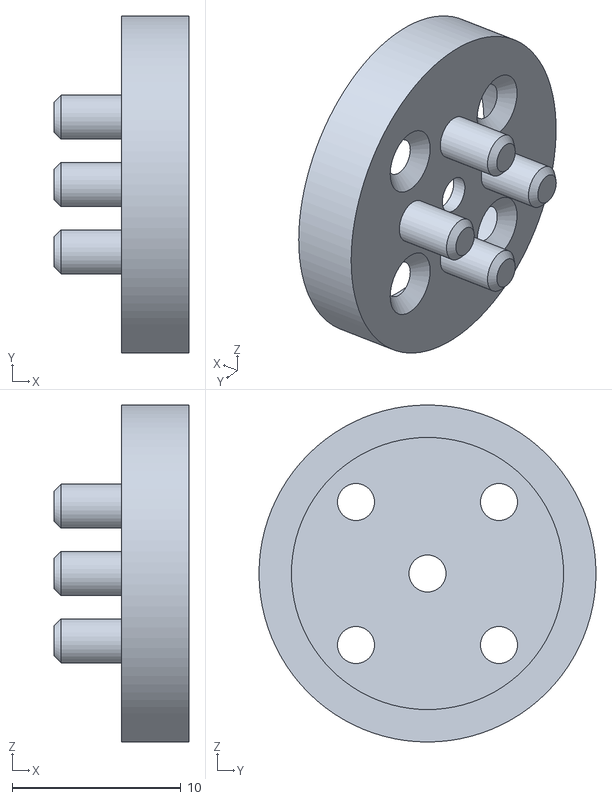
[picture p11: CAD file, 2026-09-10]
print/7-arms/boss_adapter.stl
8.00 x 20.0 x 20.0

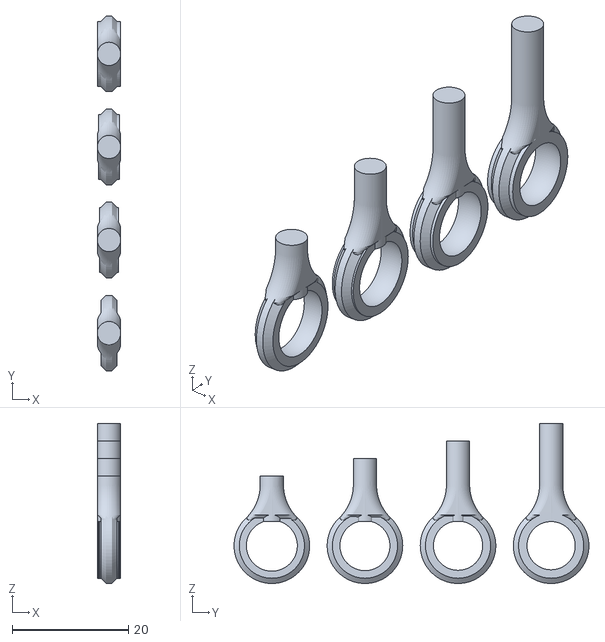
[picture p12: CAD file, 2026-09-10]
print/1-test-prints/eye_hug_test.stl
4.00 x 61.0 x 27.5

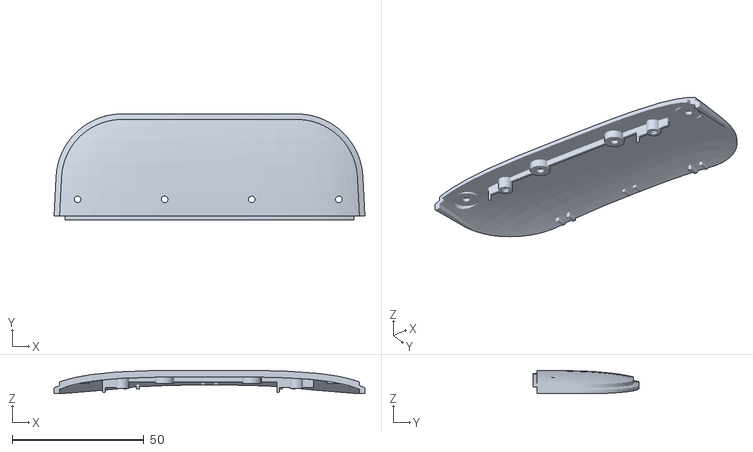
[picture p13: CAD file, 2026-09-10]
print/2-head-and-neck/head_mic.stl
117.9 x 40.2 x 8.90

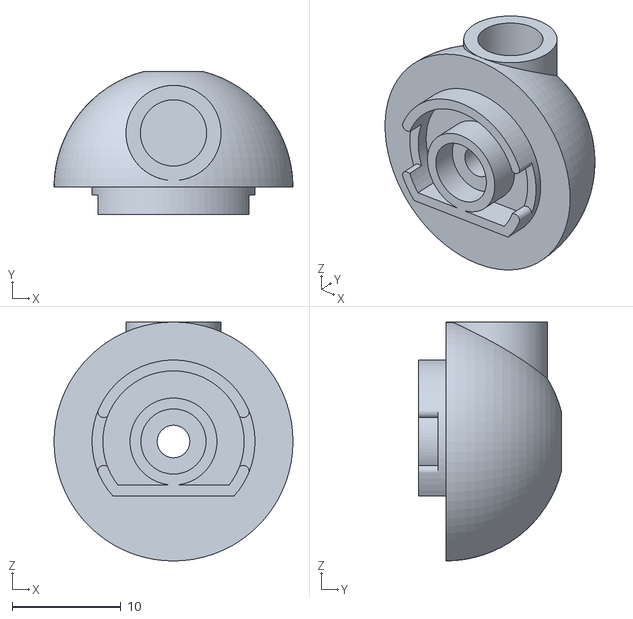
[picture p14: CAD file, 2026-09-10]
print/3-antennae/antenna_body.stl
22.0 x 13.1 x 22.0

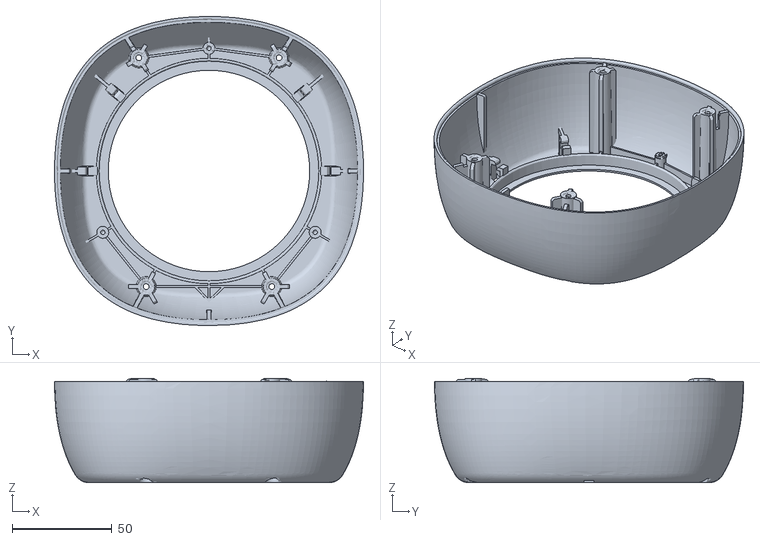
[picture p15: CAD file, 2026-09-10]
print/4-body/body_down.stl
155.0 x 155.0 x 52.3

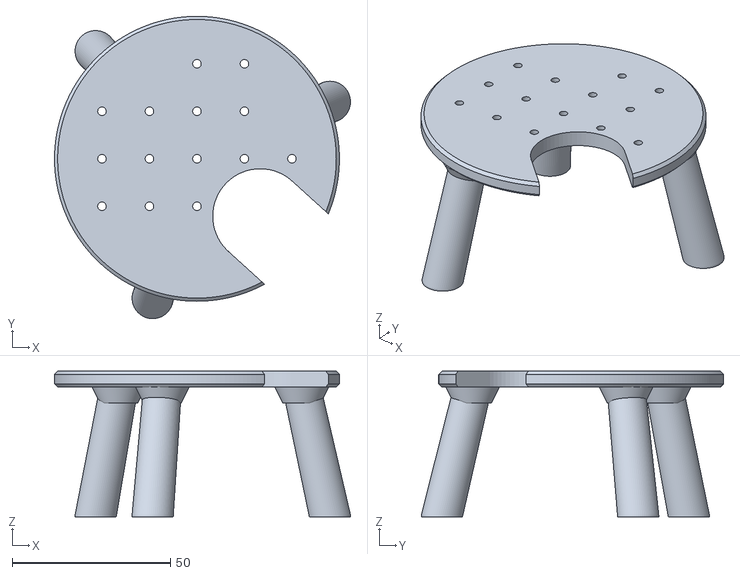
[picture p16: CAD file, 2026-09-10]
print/5-base/base_shelf.stl
93.5 x 95.5 x 46.0

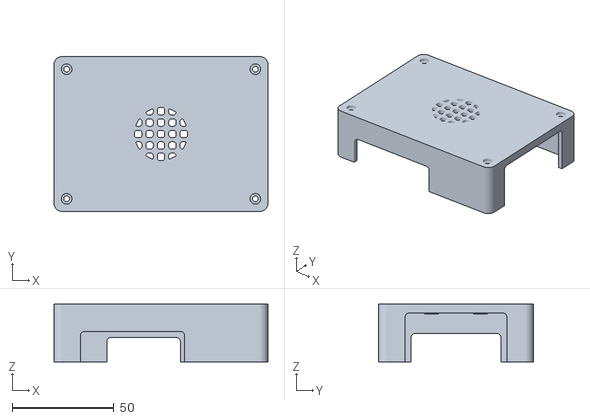
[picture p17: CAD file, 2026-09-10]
print/6-pi-case/pi5_cover.stl
105.0 x 76.0 x 28.4

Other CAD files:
print/7-arms/collar_2mm.stl
print/1-test-prints/coupon_joints.stl
print/2-head-and-neck/s10_face_cap.stl
print/3-antennae/antenna_holder_r.stl
blender/reachy_head_starter.blend
print/1-test-prints/hand.stl
print/2-head-and-neck/arm_30mm.stl
print/2-head-and-neck/head_back.stl
print/2-head-and-neck/neck_reference.stl
print/2-head-and-neck/rod_v6_eye_rod_122mm.stl
print/2-head-and-neck/s10_face_plate.stl
print/2-head-and-neck/stewart_tricap.stl
print/3-antennae/antenna_interface.stl
print/5-base/base_body.stl
print/5-base/base_top.stl
print/5-base/u2d2_tray.stl
print/5-base/yaw_rotor.stl
print/7-arms/arm_printed_left.stl
print/7-arms/arm_printed_right.stl
print/7-arms/belt_cover_elbow.stl
print/7-arms/belt_cover_roll_left.stl
print/7-arms/belt_cover_roll_right.stl
print/7-arms/bushing.stl
print/7-arms/collar_3mm.stl
print/7-arms/collar_4mm.stl
print/7-arms/hand.stl
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

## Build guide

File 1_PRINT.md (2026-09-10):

# Stage 1 — Print everything

**Everything gets printed before anything gets built.** Printing takes days and the build takes
hours, and a part that doesn't fit is far cheaper to find now than halfway through the
assembly. The print lead owns this stage; everyone else can help sort, clean up and label parts
as they come off the printer.

Use the files in the **`print/`** folder — in the **ollie-3d** repository, or on your team's
USB stick. They are already in millimetres and already turned the right way up, so **print
everything at 100 %, and don't rotate the arm parts**. (If you take a file straight from the
robot's main repository instead: the stock Reachy parts in `hardware/oem/` are modelled in
metres and import 1000× too small.)

**Default settings** unless a row says otherwise: **PETG, 0.2 mm layers, 3 walls, 15–20 %
infill.**

---

## 1. Test prints — before anything else

Each of these is small and answers one question that would otherwise cost a big print. R1
prints them first; the other teams print them once R1's have passed. Write every result in the
team log.

| Print | File | Question it answers | Pass when |
|---|---|---|---|
| Hug test | `eye_hug_test.stl` | How much grip does *your* printer and plastic give a ball joint? | A ball pressed into the longest-stub eye can't be pulled off by hand |
| Balls | `balls_production_9.05_x6.stl` | Are the balls the right size? | Calipers read **9.00–9.10 mm**. At 8.95 the joint holds half as well |
| One rod | `rod_v6_eye_rod_122mm.stl` | Does the snap ring hold a ball? | Ball swaged in warm (Stage 3), swivels freely, won't pull out |
| One motor arm | `arm_30mm.stl` | Does the arm fit the motor and the rod? | Sits flat on the motor's round boss, 4 × M2 screws bite, the rod bolts on |
| Yaw clamp | `yaw_clamp.stl` | Does the base's hardest joint fit the body-turn motor? | Its nose seats on the XC330's boss with no rocking. **Print it nose up** |
| Face plate | `s10_face_plate.stl` + `s10_face_cap.stl` | Does *your* S10 fit? | Test it the way it goes in the head — **charging port at the service-cap end, cable plugged in**. The phone slides in with a firm push at the end, the cap screws shut over the cable, nothing rattles or rocks |
| **Arm joint coupon** | `coupon_joints.stl` | Do the arm's two printed-in-place joints come out loose enough to turn? | After breaking them loose by hand, both joints turn with a fingertip. **This is the most important test print** — the first arm came off the bed with its elbow welded solid |
| **Hand snap** | `hand_adapter.stl` + `hand.stl` | Does the hand's snap fit your printer? | The hand pushes onto the adapter and clicks; it pulls off only with effort. An over-squashed first layer makes the snap too tight, and a snap that won't flex splits the hand |

If a test fails, **stop and tell the mentor** before printing the real parts. A fit is the one
thing only your printer can answer.

---

## 2. Print list — one robot

`print/PRINT_LIST.csv` is the same list, with a *done* column to tick off.

### Head and neck

| Part | File | Qty | Notes |
|---|---|---:|---|
| Head back | `head_back.stl` | 1 | Supports under the openings |
| Crown cover | `head_mic.stl` | 1 | **Easy to forget** — without it the top of the head is an open slot |
| Face plate | `s10_face_plate.stl` | 1 | Face **down** on the bed, no supports. Sized for a Galaxy S10 only |
| Service cap | `s10_face_cap.stl` | 1 | Tongue side down, no supports |
| Neck plate | `neck_reference.stl` | 1 | 20 % infill. Its six numbered holes take the rod tops |
| Stewart main plate | `stewart_main_plate.stl` | 1 | 20 % infill |
| Stewart tricap | `stewart_tricap.stl` | 1 | 20 % infill |
| **Rods** | `rod_v6_eye_rod_122mm.stl` | 6 (+2 spare) | **0.15 mm layers**, no supports, lying flat, 4 walls, 40 %+ infill. It must be the `v6_eye` file — see below |
| **Balls** | `balls_production_9.05_x6.stl` | 2 plates (12 balls) | As oriented (bore down), 0.10–0.15 mm layers. Print a third plate for spares |
| **Motor arms** | `arm_30mm.stl` | 6 (+2 spare) | Flat, **4 walls, 50 %+ infill** — these carry full motor torque |

> ⚠️ **The rod file is `rod_v6_eye_rod_122mm.stl` and nothing else.** The robot's main
> repository also holds older lengths and other joint styles, and one of them has been printed
> by mistake before. The right one has a raised collar around the ball hole on **both** faces.

### Antennae

| Part | File | Qty | Notes |
|---|---|---:|---|
| Antenna hub | `antenna_body.stl` | 2 | One per antenna |
| Antenna interface | `antenna_interface.stl` | 2 | One per antenna |
| Motor holder, left | `antenna_holder_l.stl` | 1 | 20 % infill |
| Motor holder, right | `antenna_holder_r.stl` | 1 | 20 % infill |

The antennae themselves aren't printed: they're stiff wire, bent by hand in Stage 3.

### Body

| Part | File | Qty | Notes |
|---|---|---:|---|
| Body top | `body_top.stl` | 1 | Supports under the openings. Long print — start early. The arms screw to it |
| Body bottom | `body_down.stl` | 1 | Supports under the openings |

### Base, yaw joint and Pi case

| Part | File | Qty | Notes |
|---|---|---:|---|
| Plinth | `base_body.stl` | 1 | **About ten hours.** Upright, no supports, 20 % infill. Turn on bridge detection (the window ceiling is a 62 mm bridge) |
| Stator (cap) | `base_top.stl` | 1 | Flat, upright, no supports, **25–30 % infill** — carries the robot |
| Rotor | `yaw_rotor.stl` | 1 | Flat, upright, no supports, **25–30 % infill** |
| Clamp / drive hub | `yaw_clamp.stl` | 1 | **Print it NOSE UP** — flat on the bed puts the nose under the bed. Keep your test print if it passed |
| U2D2 tray | `u2d2_tray.stl` | 1 | No supports |
| Shelf (optional) | `base_shelf.stl` | 1 | Disc down, legs up, no supports |
| Pi case tray | `pi5_tray.stl` | 1 | As it loads, no supports, 20 % |
| Pi case cover | `pi5_cover.stl` | 1 | **Upside down** — roof flat on the bed |

### Arms — both arms

Every arm file in the kit is **already the right way up**. The two `arm_printed` parts are the
exception to every other habit you have: **don't rotate them on the bed**, because their
joints are printed in place and the gaps in them are sized for exactly that orientation.

| Part | File | Qty | Notes |
|---|---|---:|---|
| **Arm, left** | `arm_printed_left.stl` | 1 | The shoulder fork, upper arm and forearm in **one print, with both joints printed in place**. As loaded, don't rotate. Support **on build plate only** |
| **Arm, right** | `arm_printed_right.stl` | 1 | The mirror image — not the same part. Same rules |
| Shoulder housing | `shoulder_housing.stl` | 2 | As loaded, don't rotate. It screws to the body |
| Hand | `hand.stl` | 2 | Serves both arms |
| Hand adapter | `hand_adapter.stl` | 2 | The hand snaps onto it |
| Wrist clamp | `wrist_clamp.stl` | 2 | Holds the wrist motor in its cradle |
| Boss adapter | `boss_adapter.stl` | 6 | Printed on its side, as loaded |
| Small pulley, 20 teeth | `pulley_20t.stl` | 6 | On each belted motor |
| Big pulley, 40 teeth | `pulley_40t_flange.stl` | 6 | On each joint |
| Roll belt cover, left | `belt_cover_roll_left.stl` | 1 | Flat, no supports |
| Roll belt cover, right | `belt_cover_roll_right.stl` | 1 | Flat, no supports. The mirror of the left |
| Elbow belt cover | `belt_cover_elbow.stl` | 2 | Flat, no supports. Serves both arms |
| Bushing | `bushing.stl` | 4 | Two per shoulder housing |
| Pitch shaft | `shaft_pitch_44mm.stl` | 2 | **Lying down** — stood up, it snaps along its layers |
| Shaft collars | `collar_2mm.stl`, `collar_3mm.stl`, `collar_4mm.stl` | 2 each | Shims for the pitch shaft. Print all three sizes; Stage 3 uses whichever fits |

Three rules for the two `arm_printed` parts, all learned from arms that came off the bed stuck:

- **Support on build plate only.** A slicer allowed to support *everywhere* will try to fill the
  0.4–0.7 mm gaps inside the joints, and a joint with support inside it never moves.
- **If the slicer offers to "repair", "merge" or "make solid", say no.** Each file is six separate
  pieces on purpose — the gaps between them *are* the joints.
- **Don't over-squash the first layer.** It eats the joint's clearance on its own.

**Weigh the first `arm_printed`** as it comes off: about 62 g. If it's far off that, tell the
mentor — the arm's strength numbers assume it.

### Do **not** print

- `head_front.stl` — replaced by the S10 face plate.
- `body_foot.stl` and `body_turning.stl` — replaced by the printed base and yaw joint.
- `pitch_fork.stl`, `upper_arm.stl`, `forearm.stl` — these are the arm's parts drawn separately
  for the 3D preview. They can never be joined; `arm_printed` is the file.
- `shoulder_spine.stl` — it ties the two shoulders together for an arm built on its own. On this
  robot the shoulders screw straight to the body shell instead.
- Anything in the main repository's `hardware/oem/reference/` — those are models of parts you
  **buy**.

None of these are in `print/`, which is the easiest way to avoid printing them.

### How much plastic

One robot is about **1.5 litres of solid plastic** — 1.2 litres for the head, body and base and
0.35 for the two arms (measured off the files). At the infills above that prints at roughly
**1.3 kg of PETG per robot**. Test pieces, spares and reprints add about half as much again, so
**order about 12 kg of PETG for six robots**.

---

## 3. Label everything

As each part comes off the printer: clean off supports and brims, then write the robot number
on a hidden face in pencil or marker, and put it in the robot's bin. Left and right parts go in
separate bags marked **L** and **R** — the left and right arm parts look alike and are not the
same.

### ✅ Checkpoint 1

- [ ] Every test print passed, and the results are in the team log
- [ ] Every part on the print list is printed and ticked off in `PRINT_LIST.csv`
- [ ] Both `arm_printed` parts weighed, and their joints not yet forced (Stage 3 breaks them loose)
- [ ] Every part labelled with the robot number; left and right arm parts bagged separately

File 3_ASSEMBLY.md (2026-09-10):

# Stage 3 — Assembly

**The Pi stays on the bench beside you for this whole stage,** with its monitor and keyboard,
the U2D2 plugged in, and the motors on the Power Hub. The head's motor arms are fitted while the
Pi tells you exactly where each motor is, and the head's "level" is recorded on the Pi.

The stock Reachy parts (the motor cages, the neck, the body) go together as the official
**[Reachy Mini assembly guide](https://huggingface.co/spaces/pollen-robotics/Reachy_Mini_Assembly_Guide)**
shows. This chapter says where our robot is different, what order to work in, and what has gone
wrong before.

| Step | What | Who |
|---|---|---|
| [1](#1-rods-balls-and-motor-arms) | Rods, balls and motor arms | Mechanical lead |
| [2](#2-the-head-motors-and-neck) | Head motors and neck, and recording "level" | Mechanical lead + mentor |
| [3](#3-antennae) | Antennae | Mechanical + motors |
| [4](#4-the-face-plate) | The face plate | Mechanical lead |
| [5](#5-the-arms) | The arms | Mechanical lead |
| [6](#6-the-arms-onto-the-body) | The arms onto the body | Mechanical lead + mentor |
| [7](#7-the-base-and-yaw-joint) | The base and the yaw joint | Mechanical lead |
| [8](#8-power-and-cables) | Power and cables | Motors lead + mentor |

> **One program on the motors at a time.** Nothing stops two programs driving the motors at
> once, and they fight. Run one motor command at a time, and never while the robot software is
> running in another Terminal.

---

## 1. Rods, balls and motor arms

The head hangs on six rods. Each rod has a ball joint at **both ends**: a printed ball snapped
into a ring in the rod. Twelve balls for six rods.

**Check before you start.** It must be `rod_v6_eye_rod_122mm.stl` — there is a raised collar
around the ball hole on **both** faces. And **measure every ball with calipers: 9.00–9.10 mm.**
A ball printed small holds half as well; a ball printed big never seats. Sort out any that are
off.

### Swage the balls in (mentor — hot water)

The ball is a tight fit on purpose — that tightness is what keeps the rod on the head.

1. Heat water to **80–90 °C** (PETG needs the lower end).
2. Hold the rod's eye in the water for about 20 seconds (tongs).
3. Push the ball through the ring — it goes in with a firm squeeze, not a click.
4. **Work the joint round in every direction while it cools**, so the ring sets to the ball's
   shape instead of just gripping it.

Push each ball in **once**. Every time a ball is pulled out and pushed back the ring stretches a
little. If a rod feels loose, print a new rod.

### Motor arms

Clean the four small holes and the tip hole with a drill bit turned by hand. Test-fit an
M3 × 18 through the tip hole and an M3 nut into its pocket on the back. **Don't screw the arms
onto the motors yet** — step 2 says how, and the angle matters.

### ✅ Checkpoint 3.1

- [ ] 6 rods (+ spares), each with **both** balls swaged in, swivelling freely, can't be pulled off
- [ ] 6 motor arms, holes cleaned, nut fits its pocket

---

## 2. The head motors and neck

Build the six head motors (IDs 4–9) into their cages following the official guide. What is
different on our robot:

| Official guide | Our robot |
|---|---|
| Metal link rods | Printed `rod_v6` rods, 122 mm between ball centres |
| Stock motor arms | Printed `arm_30mm` arms, 4 × M2 × 5 self-tapping into the motor's round boss |
| Camera, lens and speaker in the head | **Not fitted** — the phone does all three |
| `head_front` | Replaced by the S10 face plate (step 4) |

The six head motors sit in three pairs around the centre, **facing inward**: each motor's round
output boss points at the centre column, so its arm swings in an upright plane beside the motor.
At the resting pose every arm is **level**, the two arms of a pair point **away from each
other**, and the rod's ball sits on the arm's inner face. Match the picture in the official
guide before you tighten anything.

**Which motor goes where.** The software doesn't care which cage holds which ID, but all six
robots use the same layout so they can be compared: **ID 4 drives the rod into neck hole 1,
ID 5 into hole 2 … ID 9 into hole 6** (the neck plate's holes are numbered). Write it in the
team log.

### Fitting the arms — where "level" lands matters (mentor)

A motor reports its angle as a number from 0 to 4095, and the number **jumps** from 4095 back to
0 at one point in the turn (the *seam*). If an arm's level position lands near the seam, the
software thinks the arm has spun right round when it crosses it. That happened on Ollie and
cost an arm removal to fix. So:

1. Motors in their cages, **no motor arms fitted**, the Power Hub on.
2. Send every motor to the middle of its range (2048):
   ```bash
   cd ~/reachy
   .venv/bin/python -m scripts.calibrate show
   .venv/bin/python -m scripts.calibrate home
   .venv/bin/python -m scripts.calibrate home
   .venv/bin/python scripts/motor_status.py --ids 4,5,6,7,8,9
   ```
   `show` must print a path ending in `reachy/data/motor_calibration.json`, then
   `(defaults)` — and a warning that the file is unusable. That's expected here: your robot has
   no calibration file yet, and that is what makes "home" mean 2048. `home` runs twice because a
   long move can be cut short when the script lets go. Afterwards `motor_status` should read
   about 2048 (±20) on every head motor. The motors go limp but stay where they were sent.

   ⚠️ **`show` first, every time.** It is the only `calibrate` command that moves nothing —
   every other one switches the motors on and drives them to "home" straight away.

3. Without turning the motor, fit its arm in whichever of the **four bolt positions is
   closest to level, pointing away from its pair partner**. It won't be exactly level — the bolt
   pattern only goes on in quarter turns — and that's fine.
4. Screw it down with 4 × M2 × 5 (small screws in plastic — snug, not tight).

### Record "level" — before any rod goes on (mentor)

This is the moment it's easy: six loose arms and a spirit level. With the rods on, the arms
can't be set level one at a time.

1. Hold each head motor's arm **level** — a small spirit level, or a phone level app laid along
   the arm. The motors are limp; the arms stay where you put them.
2. Read all six:
   ```bash
   .venv/bin/python scripts/motor_status.py --ids 4,5,6,7,8,9
   ```
   Write the six positions (`pos`) in the team log, in ID order.
3. **Each must be between about 1000 and 3100.** Closer to 0 or 4095 than that and the arm's
   travel crosses the seam — take that arm off, move it one bolt position, and read it again.
4. Make your robot's calibration file from the template and put your numbers in it:
   ```bash
   mkdir -p data
   cp calibration-template.json data/motor_calibration.json
   nano data/motor_calibration.json
   ```
   Replace the six `2048`s after `"neutral"` with your six readings, in ID order 4–9. Leave
   everything else alone. **Ctrl-O** then **Enter** saves; **Ctrl-X** exits.
5. Prove the file reads:
   ```bash
   .venv/bin/python -m scripts.calibrate show
   ```
   It must say **`(loaded)`** and show **your** six numbers.
6. Copy `data/motor_calibration.json` onto the USB stick as `calibration-R3.json` (your robot's
   number). It was measured on this robot and can't be made again.

From here on, "home" sends the head to **level** instead of 2048 — which is what makes it safe
to run with the rods fitted. **`show` must say `(loaded)` before any `home`.** If it ever says
`(defaults)` — a typo in the file, a missing comma — stop: with the rods on, 2048 binds the
head. (Appendix B explains the rest of the file.)

### Rods

Each rod: an **M3 × 18** goes through the bottom ball into the motor arm's tip, with the nut in
the pocket behind. An M3 through the top ball fixes it into its numbered hole under the neck
plate.

⚠️ **The one screw rule that matters.** Tighten until the ball has no wobble, then **back off a
hair until it swivels freely** under finger pressure. A clamped ball joint makes the head stiff
and stops it reaching its angles — on Ollie, over-tight neck screws were most of why the head
"couldn't get its range".

### Cables

The six head motors are daisy-chained. **Hot-glue or zip-tie every connector** so the head's
movement can't pull one half out. On Ollie, a motor dropping off the bus when a cable was nudged
was a regular fault until every connector had strain relief.

### ✅ Checkpoint 3.2

- [ ] `calibrate show` says `(loaded)` with your six level readings, all between 1000 and 3100
- [ ] The calibration file is backed up on the USB stick
- [ ] With the motors unpowered, the head moves by hand through nod, tilt and turn with no
      binding or clicking, and no rod pops off
- [ ] Every rod-top screw passes the "swivels freely" test
- [ ] A scan still finds all six head motors (the cables survived)

---

## 3. Antennae

The two antenna motors (**M077**, IDs 1 and 2) sit in the printed holders inside the back of
the head, shafts pointing backwards. The hub goes on the motor and the wire goes in the hub.

1. Build each antenna motor into its holder (left and right holders are different parts).
2. **Plug in one antenna motor (power off), then scan.** It must appear alongside the others. On
   Ollie, plugging the antennae in once killed the whole bus — every motor went silent — and the
   cause was never found. One at a time tells you immediately which one it is.
3. Send it to the middle of its range: `calibrate show` — **must say `(loaded)`** — then
   `calibrate home` twice.
4. **Make the antenna:** stiff wire (brass or steel), bent by hand with a small coil a little
   above the hub — the coil is what makes it bounce. Ollie's are in the photo on the first page.
   Measure the hole in the antenna hub and pick wire that is a snug push fit; make it about the
   height of Ollie's (the stock antenna is about 165 mm). **Round off the top end** with a file
   or a blob of hot glue — children will touch it.
5. Fit the hub, and push the wire in so it points **straight up**. That keeps the antenna's
   swing clear of the motor's seam.
6. Repeat for the other antenna, then strain-relieve both cables.
7. **Record the antennae's centre:** with both wires pointing straight up, read them:
   ```bash
   .venv/bin/python scripts/motor_status.py --ids 1,2
   ```
   Open `data/motor_calibration.json` in `nano` again and put the two readings in as the
   `center` of `antenna_left` (ID 1) and `antenna_right` (ID 2). Set each one's `min` to its
   centre minus 1024 and `max` to its centre plus 1024. Save, run `calibrate show` (must say
   `(loaded)`), and copy the file to the USB stick again.

Nothing may sit in the antennae's path: they swing through a band across the top and back of
the head.

### ✅ Checkpoint 3.3

- [ ] A scan shows 1 and 2 **and** 4–9 all at once
- [ ] Each antenna swings freely by hand (unpowered) through its whole range without hitting
      the head, and its tip is rounded
- [ ] The antennae's centres are in the calibration file, and it still says `(loaded)`

---

## 4. The face plate

The face is a **Samsung Galaxy S10** mounted sideways behind the face plate. Its screen draws
the eyes and its speaker is the voice. The plate goes on now; **the phone goes in during Stage
4**, once it has been set up and paired — it slides in from the side, so the head doesn't have
to come apart for it.

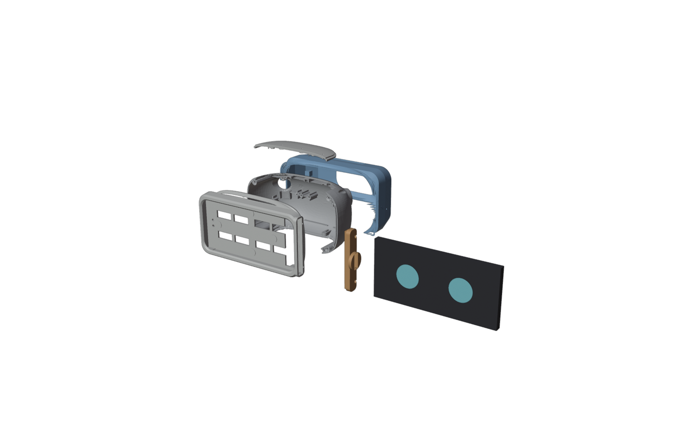
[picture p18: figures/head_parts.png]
The head, exploded


*The head, pulled apart: the stock head back (grey) with the crown cover above it, the S10 face
plate (white) in front, the service cap (orange) and the phone beside it — it slides in
sideways — and a back shell (blue) behind. The back shell is only needed for a head designed in
Stage 6.*

1. Offer the face plate up to `head_back` the way the original face went on: tabs into the six
   slots, the locating nubs register, then the **original four screws** in from the back.
2. Clip `head_mic` into the slot across the crown.
3. Keep the service cap and its two M2 × 10 screws in the bin until Stage 4.
4. **Plan the phone's charging cable now.** Ollie's phone stays plugged in: a USB-C cable leaves
   the head beside the service cap and runs down behind the head into the body (you can see it
   in the photo on the first page). It needs enough slack for the head to nod, tilt and turn the
   whole way, and it must be tied where it can't catch in the neck rods. It ends at the phone's
   USB charger in the base (step 8).

⚠️ **Weight.** The phone is 157 g on the front of a head held up by six small motors. Don't add
anything to the head that isn't in the design.

### ✅ Checkpoint 3.4

- [ ] Face plate on with its four screws; the top of the head is closed (`head_mic` fitted)
- [ ] The phone's cable route is planned and the cable is in the bin

---

## 5. The arms

Each arm has four motors: **shoulder pitch** (swings the arm forward and back), **shoulder
roll** (lifts it out to the side), **elbow**, and **wrist**. The first three drive their joints
through belts at 2:1; the wrist drives the hand directly.

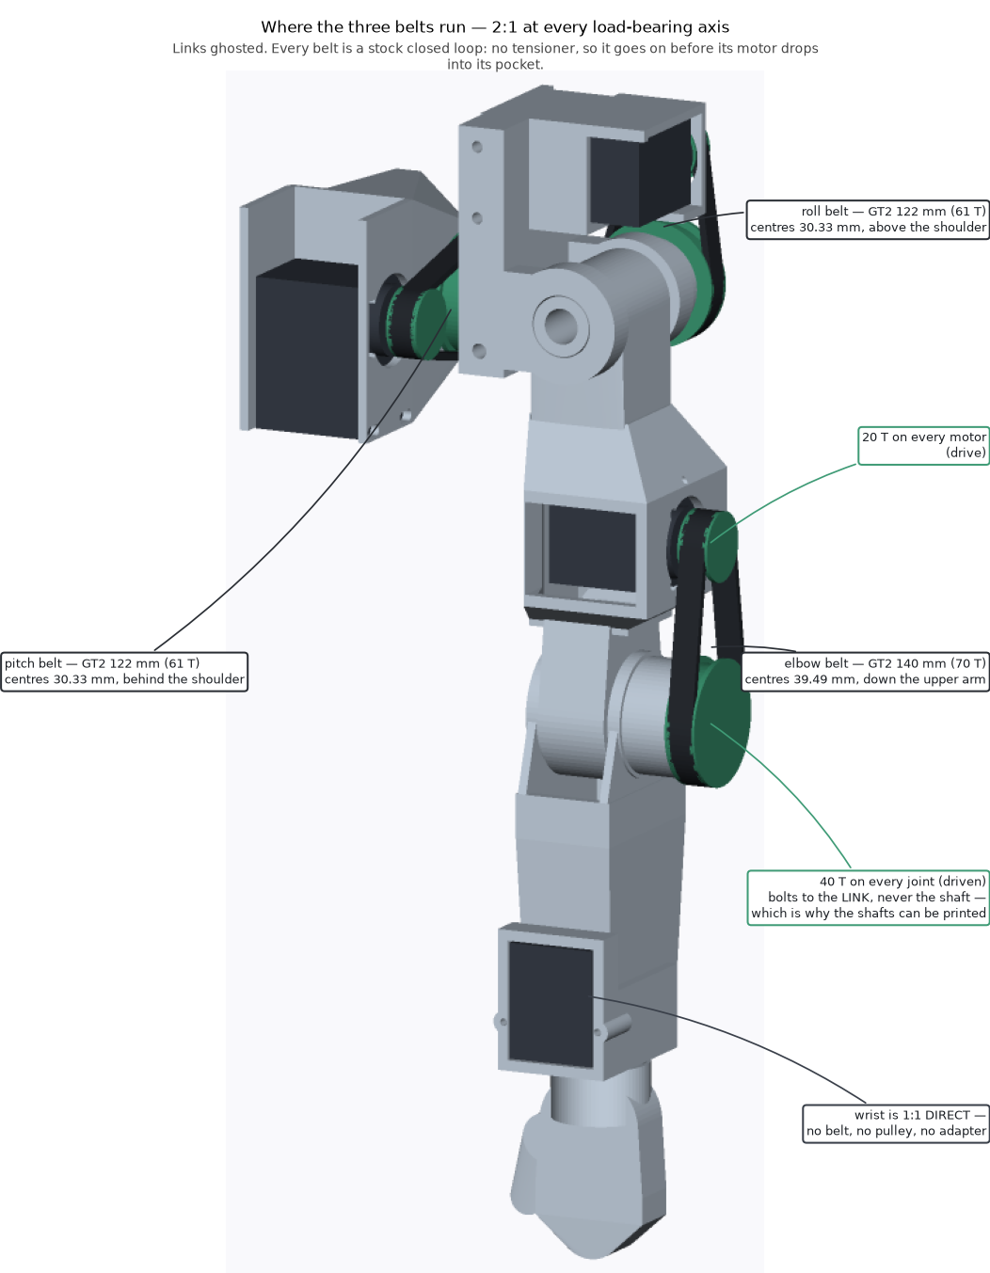
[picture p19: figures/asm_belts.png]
Where the three belts run


*One arm, with the belts shown: the pitch belt behind the shoulder, the roll belt above it, the
elbow belt down the upper arm. Every belt is a closed loop with no tensioner, so it goes on
before its motor goes into its pocket.*

**Before you start:**

- **Sort the parts into two piles, left and right.** `arm_printed`, the roll belt cover and the
  motors (14–17 right, 18–21 left) are different for each side. On a finished arm, whichever
  side it is, **the elbow belt runs down the outboard face of the upper arm, and the roll pulley
  faces forward.** If your dry fit puts them the other way, you have the other arm's part.
- **Which motor goes where** — check the labels from Stage 2 as each one goes in:

  | Joint | Right arm | Left arm | Where it sits |
  |---|---:|---:|---|
  | Shoulder pitch | 14 | 18 | In the shoulder housing |
  | Shoulder roll | 15 | 19 | On the fork, above the shoulder |
  | Elbow | 16 | 20 | Lying flat in the upper arm |
  | Wrist | 17 | 21 | In the forearm's cradle |

- **The belts** (per arm): two **122 mm** GT2 loops (pitch and roll — the same belt, so nothing
  to mix up) and one **140 mm** loop (elbow), all 6 mm wide.
- **No need to position the arm motors first.** Unlike the head, the arm's zero is recorded
  after the arm is built (Stage 4), so the motors can be at any angle when the belts go on.

**Work from the hand inward.** A closed belt has no slack, so each one is looped over both its
pulleys while the motor is loose in your hand, and only then does the motor slide into its
pocket. Every step below keeps the screwdriver's path open for the next.

### Step 1 — Break the printed joints loose

The `arm_printed` part came off the printer with its elbow and shoulder joints already made.
Straight off the bed the gaps may be lightly stuck together. **Work the elbow first, gripping the
forearm close to the joint** — a long lever on a stuck joint snaps a 3 mm cheek off instead of
freeing it, and that is exactly how the first arm was lost. Then work the shoulder. Both should
turn by fingertip. **If either won't move at all, stop** and tell the mentor — don't force it.

### Step 2 — Bushings and the pitch pulley

1. Press the **two bushings** into the shoulder housing, one from each end face of its bearing
   barrel. Press them square in a vice with a flat plate. **Test the first one**: it should need
   a firm push and then stay put, and the printed shaft should turn freely in it afterwards.
2. **Bolt the pitch 40-tooth pulley onto the fork now** — its inboard face (the side that will
   face the body), 3 × M2 × 16 straight into the printed hub. Once the arm is in the housing
   those screws can't be reached. Snug, not tight: you're cutting a thread in plastic. The
   pulley's flange must sit flat on the hub face with no gap.

### Step 3 — Drive stacks (pitch, roll and elbow motors)

For each of the three belted motors, in your hand:

1. `boss_adapter` over the motor's round boss, 4 × M2 × 5 **countersunk**. Each head ends up
   flush or just below the plate's top face. Snug only.
2. `pulley_20t` drops onto the adapter's four drive pins.
3. One **M2 × 8** down the centre. Its head sits at the **bottom** of the pulley's socket, not
   flush at the top — the space above it is where a belt cover's pin goes.

Spin it and watch the flange: any wobble means the adapter isn't seated on the boss.

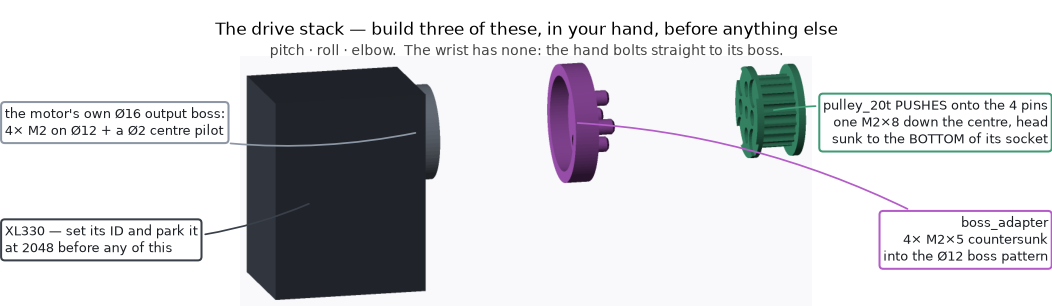
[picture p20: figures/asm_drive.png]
The drive stack


*The drive stack: motor, boss adapter, 20-tooth pulley, centre screw.*

### Step 4 — Hand and wrist

1. Drop the wrist motor (17 / 21) into the forearm's cradle from the back, and bolt the
   `wrist_clamp` across the opening with 2 × M3 × 12.
2. `hand_adapter` onto the wrist motor's boss — 4 × M2 × 5 countersunk, **while you can still
   reach them**.
3. Push the hand onto the adapter until the snap clicks. No screws in the hand.

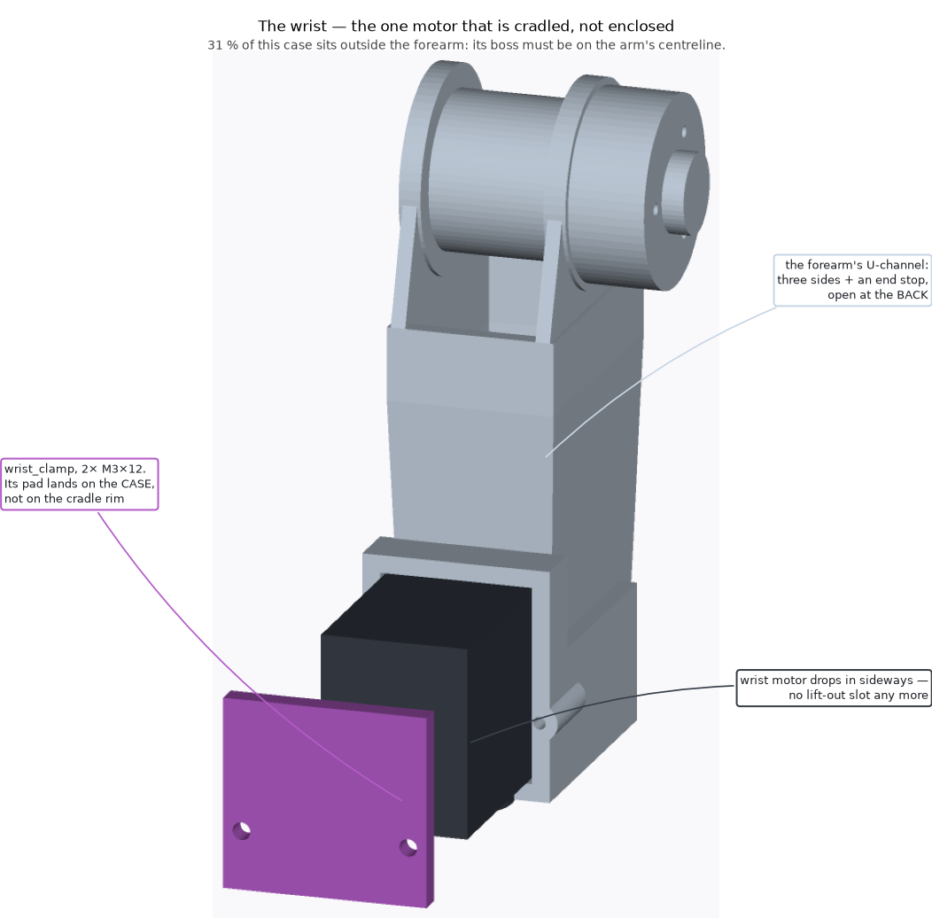
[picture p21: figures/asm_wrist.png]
The wrist cradle


*The wrist motor drops into the forearm's cradle from the back and the clamp bar holds it.*

### Step 5 — Elbow

1. Loop the **140 mm** belt over a 40-tooth pulley and over the elbow motor's 20-tooth pulley,
   motor still loose.
2. Bolt that 40-tooth pulley to the forearm's elbow hub — 3 × M2 × 16, on the **outboard**
   face — with the belt still around it.
3. Slide the elbow motor (16 / 20) into the pocket in the upper arm **from the back** — it lies
   flat, long side front to back. Fix it with 2 × M2 × 6 and washers through the front face.

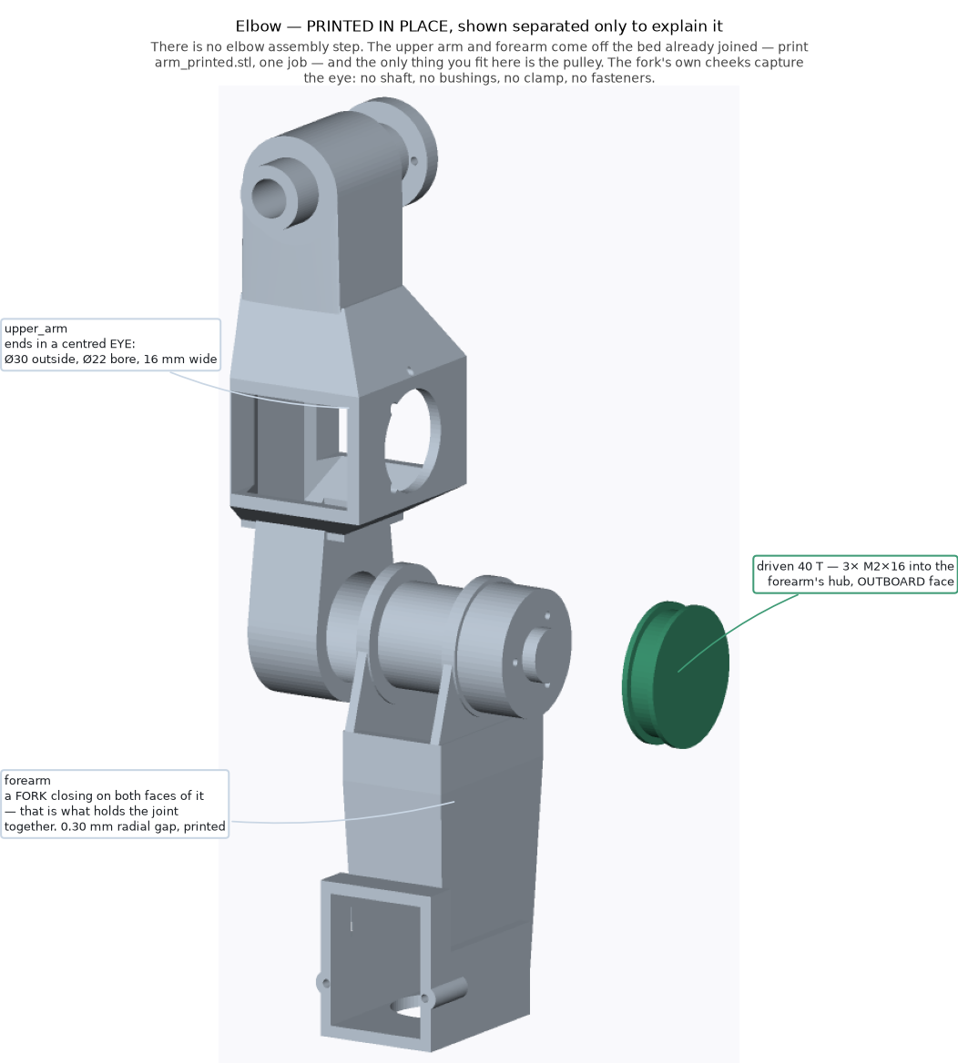
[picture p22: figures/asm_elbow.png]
The elbow, exploded


*The elbow: the belt goes on first, then the motor slides in from the back.*

### Step 6 — Shoulder roll

1. Loop a **122 mm** belt over the roll motor's 20-tooth pulley, and over a 40-tooth pulley.
2. Bolt that 40-tooth pulley to the collar on the **far side of the fork's outer cheek** —
   3 × M2 × 16. It drops onto a round spigot and should go on with a firm push and no rock.
3. Drop the roll motor (15 / 19) onto the fork's cradle from the outside, and fix it with
   2 × M2 × 20 through the back face.

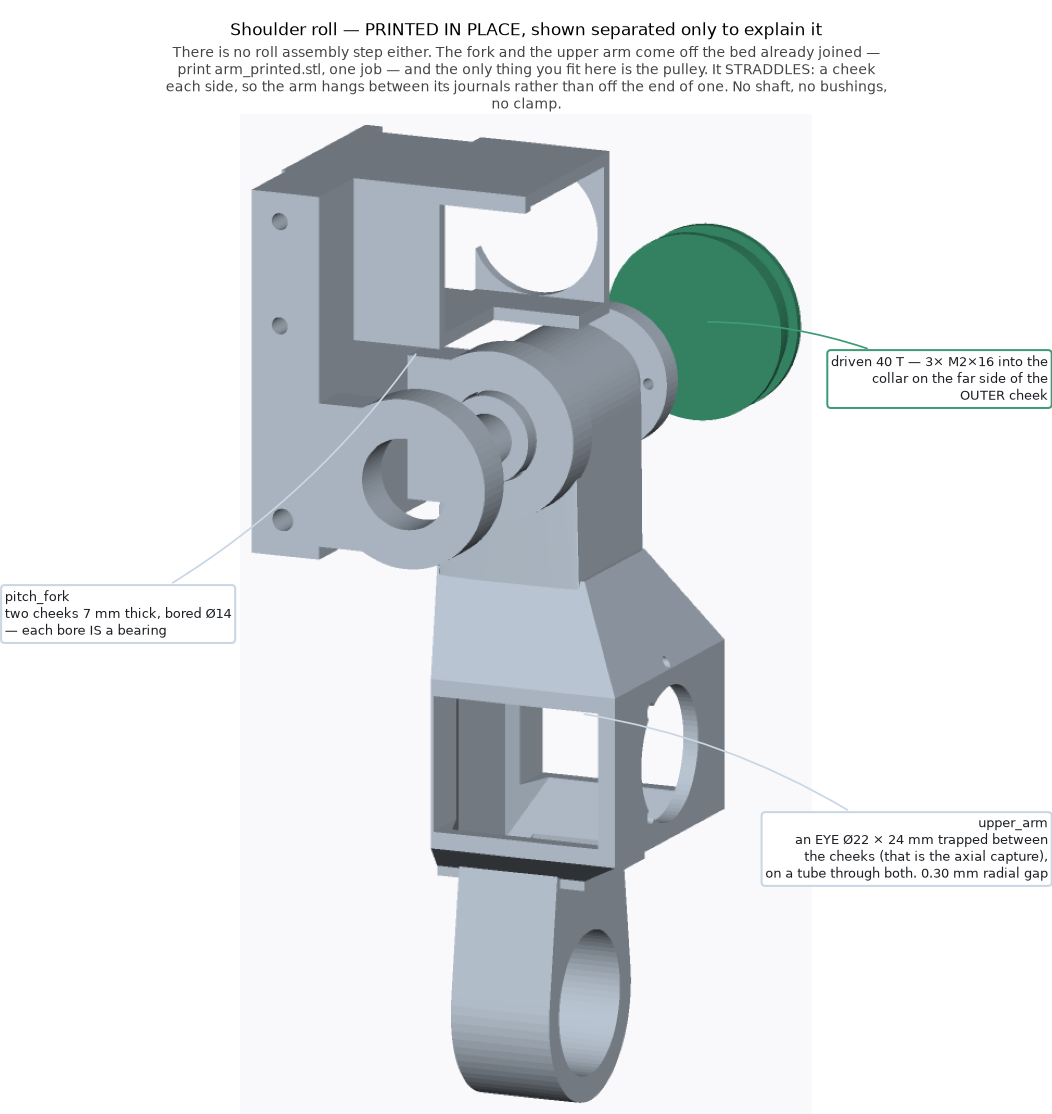
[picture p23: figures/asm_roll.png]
Shoulder roll, exploded


*Shoulder roll: the belt over both pulleys, then the motor down onto the fork's cradle.*

### Step 7 — Shoulder pitch

1. Loop a **122 mm** belt over the fork's pitch pulley (fitted in step 2) and the pitch motor's
   20-tooth pulley.
2. Slide `shaft_pitch_44mm` in **from the body side**: through both housing bushings, through the
   pulley, and into the fork's pitch hub. Fit whichever collar (2, 3 or 4 mm) stops the shaft
   sliding end to end.
3. **Pin the shaft to the fork** (mentor): drill **2.5 mm straight up from the underside of the
   fork's back plate**, through the hub and the shaft together, and drive in an M3 self-tapping
   screw or a 2.5 mm pin. This is the only thing that stops the shaft walking out. Don't skip it.
4. Lower the pitch motor (14 / 18) into the housing's bay **from above**. Start its two M2 × 6
   screws in the lower pair of slots, finger tight.
5. **Tension the belt:** put a small flat screwdriver through the little window in the front
   of the bay and lever the motor backwards against the belt, then tighten the two screws while
   you hold it there. A fraction of a millimetre is normal.

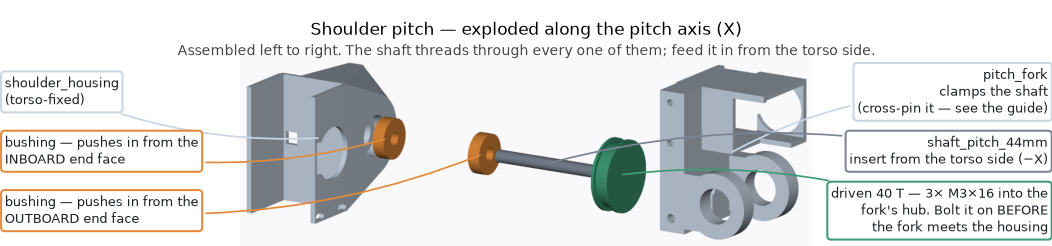
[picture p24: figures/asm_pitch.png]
Shoulder pitch


*Shoulder pitch: the shaft goes in from the body side; the motor drops into the housing from
above. (The picture's label says M3 × 16 for the big pulley — that's out of date: it's
M2 × 16, as in step 2.)*

### Step 8 — Belt covers

Last, once both belts are on and both motors are fixed. Each cover pins into the bore of both its
pulleys and is held by one **M2 × 16 countersunk** screw.

1. Line the big pin up with the 40-tooth pulley's bore and the small pin with the 20-tooth
   pulley's socket, and drop it on. **Both pins are loose, and that's right** — each pulley
   keeps turning under its pin. Never force a cover on.
2. Drive the screw through the cover into the fork (roll) or the upper arm (elbow). **Nip it up,
   don't crank it.**
3. **Spin each pulley with a fingertip before and after the screw goes in.** Stiff before means a
   pin is too tight in its bore; free before and stiff after means the screw is too tight.

The pitch belt has no cover — it's walled in by the body.

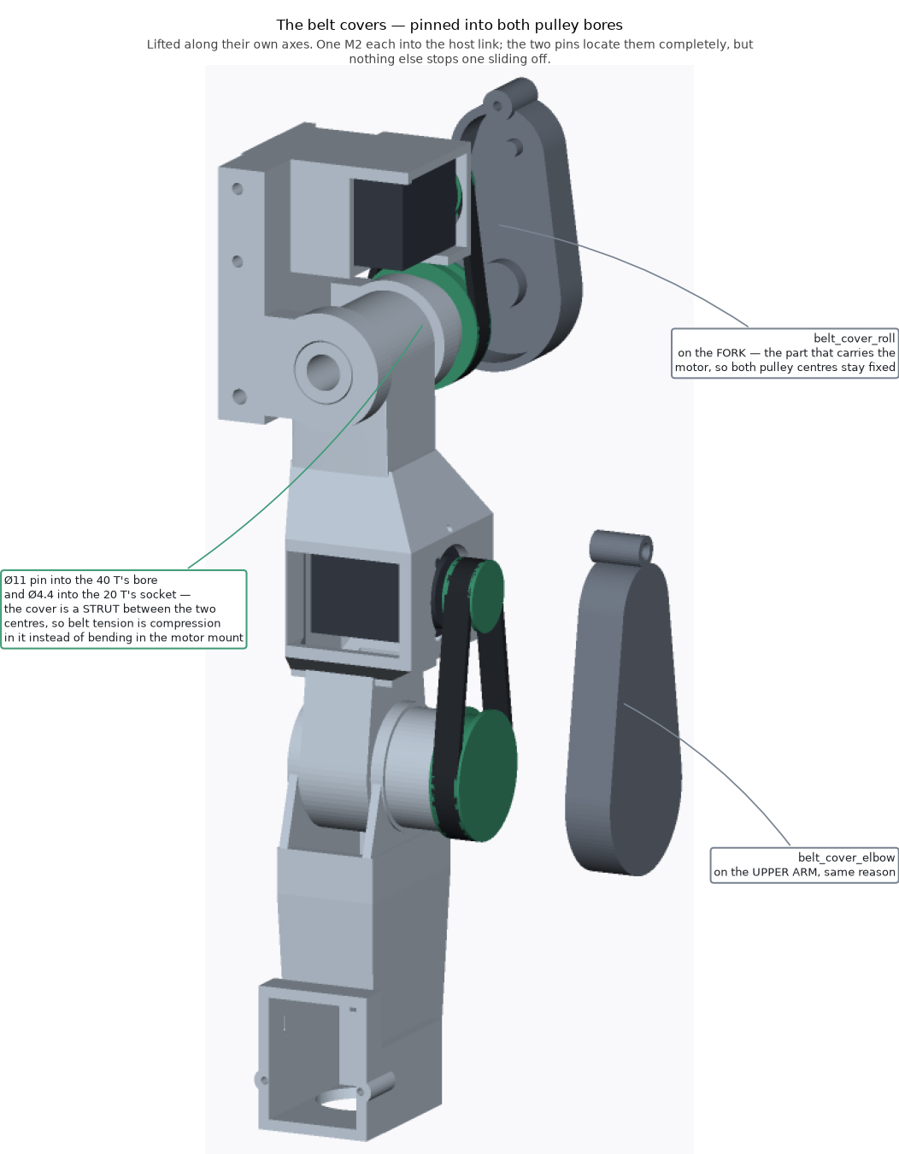
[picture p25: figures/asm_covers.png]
The belt covers


*The two belt covers, lifted off. Each one is also a strut that holds its two pulleys apart.*

**Belt tension, all three:** a belt should give a couple of millimetres under a firm thumb in the
middle and make a dull thud, not a note. Too tight wears out the motor's bearings.

### ✅ Checkpoint 3.5

- [ ] Both arms built, every motor in the right place for its label
- [ ] With the motors unpowered, every joint turns by hand through its range with nothing rubbing
      and no belt jumping teeth
- [ ] Each pulley turns under its belt cover
- [ ] The pitch shaft is pinned on both arms
- [ ] A scan finds 14–17 and 18–21

---

## 6. The arms onto the body

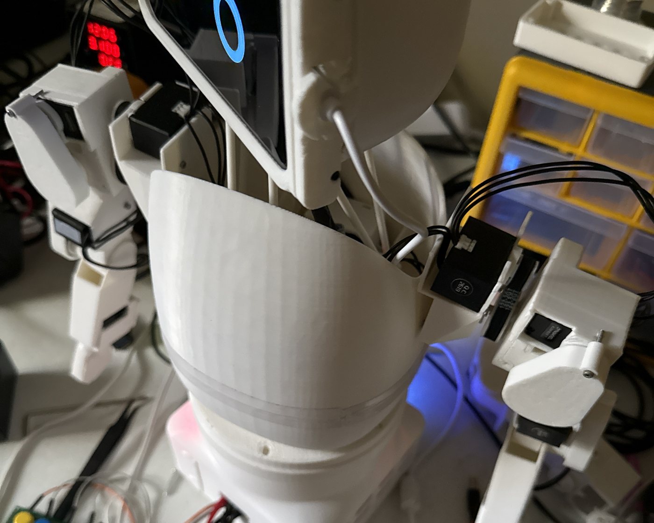
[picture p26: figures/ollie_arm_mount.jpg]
Ollie's shoulders, screwed to the top of the body


*Ollie's shoulders: each shoulder housing is screwed to the top of the body, where the shell
narrows, and the arm hangs outside it. The motor cables go in over the top.*

The shoulders screw straight through the body shell. There's no printed bracket for this —
Ollie's were fitted by hand — so **R1 works out the exact position first, with the mentor, and
writes it down** (distance below the top rim, distance from the front seam) so all six robots
match. After that, a paper template taken off R1's body lets the other teams mark and drill
their shell before anything is inside it.

1. Hold each arm where Ollie's is: its shoulder housing at the top of the body where the shell
   narrows, one on each side and level with each other, the arm hanging outside the shell.
2. Mark the housing flange's four holes onto the shell, then drill **3.2 mm** (a small pilot
   hole first). Clean off the swarf, and keep it out of the head motors below.
3. Bolt each housing on with **4 × M3 screws and nuts** (R1 confirms the length — about 12 mm).
4. Run both arms' motor cables in over the top of the body to the motor chain, as in the photo.
   Leave enough slack for the arm's full swing, and strain-relieve every connector.

### ✅ Checkpoint 3.6

- [ ] Both shoulders solid on the body, at the same height, with no rocking
- [ ] With the motors unpowered, the head moves by hand through its whole range without touching
      either shoulder or an arm cable
- [ ] Each arm swings through its range without hitting the body
- [ ] A scan still finds 1–9 and 14–21

---

## 7. The base and yaw joint

The robot stands on a printed plinth with a **6816 bearing** on top. The body-turn motor (ID 3)
hangs under a bridge in the top of the base and turns the rotor directly. Cables go straight up
through the middle of the bearing.

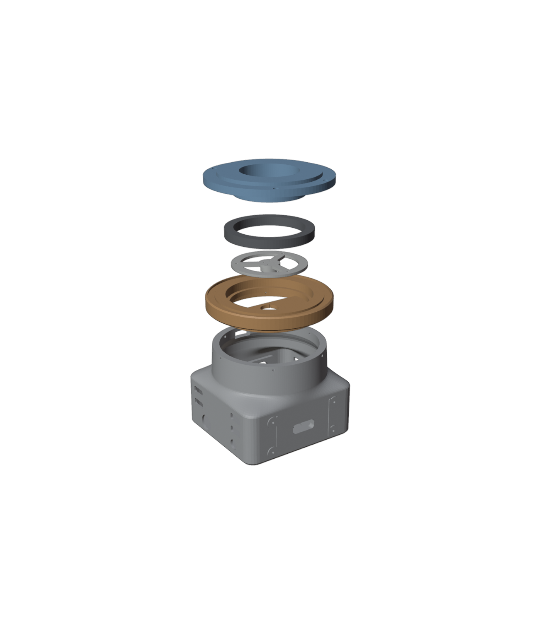
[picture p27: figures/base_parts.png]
The base and yaw joint, exploded


*The base, pulled apart, bottom to top: the plinth (grey), the stator cap (orange) with the yaw
motor hanging under its bridge, the clamp and drive hub (white), the 6816 bearing (dark), and
the rotor (blue) that the body sits on.*

Do it in this order — it's the order in which every screw can still be reached:

1. Electronics into the plinth (step 8 says what goes where). The top opening is ⌀117 mm.
2. **Yaw motor** up under the cap's bridge, boss through the hole: 4 × M2 × 8 down through the
   bridge. Send it to the middle of its range first (`calibrate show` must say `(loaded)`, then
   `calibrate home` twice), and **don't turn it by hand after that**. When you choose which
   holes line up in steps 3 and 6, pick the combination that leaves the body **facing forward**
   (within about 15°). The body turns 90° each way; starting from the middle keeps that clear of
   the motor's seam.
3. **Clamp / hub** down onto the motor's boss: 4 × M2 × 10.
4. **Bearing** into the cap's pocket.
5. **Rotor** spigot down through the bearing onto the clamp.
6. 3 × M3 × 8 countersunk **up from below** at 30°, 150° and 270°, in the hole combination you
   chose in step 2.
7. **Four brass spacers** into the rotor's pockets, then lower the **body** onto the rotor's
   ring. The body's own four clamshell screws (the longer ones) go **up from under the rotor**,
   through the spacers, into the body — one set of screws holds the body shut and holds it on.
8. **Cap into the plinth:** 6 × M3 × 14, sideways through the drum wall.
9. **Record the body's centre:** with the body facing straight forward, run
   `motor_status.py --ids 3` and put the reading into the file as the `center` of `body_yaw`,
   with `min` 1536 below it and `max` 1536 above it (both must stay inside 0–4095). Save, `show`
   must say `(loaded)`, and back the file up to the USB stick.

To service the base later, undo the six screws in step 8 and the whole robot lifts off with the
joint intact.

**Cable loop.** The body turns up to 90° each way, carrying the head, the arms and every cable
with it. Leave enough slack in the cables passing up through the middle that a full turn each
way pulls on nothing, and tie them so they can't rub on the bearing or a printed edge.

### ✅ Checkpoint 3.7

- [ ] With the yaw motor unpowered, the body turns smoothly by hand 90° each way with all cables
      connected — no rubbing, no tugging
- [ ] The body doesn't rock on the rotor
- [ ] The body's centre is in the calibration file

---

## 8. Power and cables

```
 wall ─ 12 V brick ─┬─► 12→5 V converter ──► U2D2 Power Hub ──► all 17 motors
                    └─► 12→5 V USB charger ──► USB-C cable up through the body ──► phone

 wall ─ official Pi 27 W supply ──► Raspberry Pi 5 ──USB──► U2D2 ──► Power Hub (data)
```

The 12 V side — the brick, the fuse, the switch and the converters — is **mentor work** and is
wired and measured as [Appendix B](MENTOR_SETUP.md) describes. The Pi keeps its own official
supply: a general-purpose 5 V supply measured too low on Ollie and made the Pi crash.

1. **Mentor: measure the motor supply before any motor is connected** — probes on the Power
   Hub's input, power on: **about 5.0 V**. If it says 12, stop.
2. Power Hub into its tray (4 × M3 from above), tray into the rails in the plinth. The
   converters go in the plinth too.
3. The Pi goes in its case: Active Cooler on, Pi on the standoffs (4 × M2.5 × 8), cover on.
   The case **stands on the table** beside the plinth and bolts to its right side
   (4 × M3 × 16) — the screws only locate it, the table carries it.
4. Short USB cable from the Pi to the U2D2, inside the base.
5. Motor chain from the Power Hub up through the yaw joint to the body, then on to the head and
   both arms.
6. The phone's charging cable from the USB charger up through the yaw joint and the body to the
   head (the route you planned in step 4).
7. **Tie down every cable in the base.** Nothing loose, nothing crossing the yaw joint or a
   printed edge where it can rub. On Ollie, the motors once lost power for eleven minutes and came
   back only when the cables in the base were moved — most likely a short from a loose wire.

Leave the monitor and keyboard on the Pi: you need them for Stage 4.

### ✅ Checkpoint 3.8

- [ ] 5 V measured at the Power Hub before the motors were connected
- [ ] With the Pi running and the motors powered, a scan from the Pi finds all 17 motors
- [ ] No loose cable anywhere in the base; the body still turns freely 90° each way

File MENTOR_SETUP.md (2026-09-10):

# Appendix B — Mentor notes

This appendix is for the adults. It covers what has to be ready before the students start, and
the parts of the build that can break hardware if they're done in the wrong order.

---

## Before day one

### 1. The student kit — one USB stick per team

On a computer with the robot's main repository (`redarchlabs/reachy-the-robot`):

```bash
.venv-cad/bin/python docs/student-build/make_pdf.py
.venv-cad/bin/python scripts/make_student_kit.py
```

That writes `dist/reachy-student-kit/` (and a zip of it). Copy the folder onto six USB sticks
labelled R1–R6. The kit holds the print files (all millimetres), this book, the Blender starter,
and `software/reachy-software.tar.gz`: the robot software as committed, plus the 3D models and
browser libraries (Blockly, three.js) its pages need. It deliberately holds **no** `.env`, no
calibration and no voice models — a student robot starts clean.

The same print files, this book's chapters and the Blender starter are published to the
**ollie-3d** repository, without the software:
`.venv-cad/bin/python scripts/export_ollie3d.py <your ollie-3d checkout>`, then commit and push
there.

### 2. The SD cards

Raspberry Pi Imager → **Raspberry Pi 5** → **Raspberry Pi OS (64-bit)**, the version with the
desktop. In the Imager's settings:

- hostname `reachy-r1` … `reachy-r6`;
- a username and password — write them down; the install in Stage 2 asks for the password;
- the wifi the robots will use, and your country, time zone and keyboard;
- SSH, if you want to reach the Pis from a laptop (optional — nothing in the book needs it).

Label each card with its robot number.

### 3. The network

Two things are needed from the wifi, and school networks often give only the first:

1. **Internet**, for the install in Stage 2 (system packages and Python packages).
2. **Devices that can reach each other.** The phone in the head, the Pi and (for the VR test)
   the headset all talk to each other directly. Many school networks block that ("client
   isolation"), and it shows up as a phone that simply can't open the robot's page. If so, bring
   a travel router and put the robots on its wifi.

Reserve each Pi's address in the router (a DHCP reservation) so it never changes — the phone's
home-screen icon has the address in it.

### 4. Don't deploy student robots from Ollie's working copy

`scripts/deploy_pi.sh` was written for Ollie. On any Pi that doesn't have them yet, it seeds two
files from the working copy it runs in: Ollie's **`.env`** (with its credentials) and Ollie's
**`data/motor_calibration.json`** — motor positions measured on a different head, which can drive
a student head against its own rods and break a printed rod or motor arm. Student robots are
installed from the kit, on the Pi, as Stage 2 describes. If you ever do use `deploy_pi.sh` for a
student Pi, run it from a fresh clone, which has neither file.

---

## The power wiring (12 V)

```
 wall ─ 12 V brick ─[10 A fuse]─[switch]─┬─► 12→5 V converter, 10 A ──► U2D2 Power Hub ──► 17 motors
                                         └─► 12→5 V USB charger ──────► phone, up the neck

 wall ─ official Pi 27 W supply ──► Raspberry Pi 5   (its own supply — never the 12 V board)
```

Build it from **`hardware/power/BUILD.md`** in the main repository, which puts a meter reading between
every step. The student robots use two of its outputs: the motor converter and the phone's USB
charger. The Pi stays on its official supply — a general-purpose 5 V supply measured 4.99 V on
Ollie, close enough to the Pi's cut-out that it crashed.

- Fuse the **+12 V** leg, not ground. Nothing above 12 V goes inside the base.
- **Set and measure the motor converter at 5.0 V with nothing connected**, then at the Power
  Hub's input, and only then connect motors. A 12 V mistake here destroys every motor on the bus.
- **Seventeen motors on one 10 A converter** is what Ollie runs. A driven arm holds itself up
  against gravity, so the converter works hardest while the arms are moving. Feel it after the
  30-minute run in Stage 5, which includes arm shows: warm is fine; too hot to hold means the
  arms need a converter of their own.
- Tie every wire down. Ollie's motors once lost power for eleven minutes and came back only when
  the cables in the base were moved — most likely a short from a loose wire.

---

## The calibration file

Students write it in Stage 3 from `calibration-template.json`, which is in the software:

```json
{
  "joints": {
    "antenna_left":  {"id": 1, "center": 2048, "ticks_per_deg": 11.4,
                      "sign": 1, "min": 1024, "max": 3072},
    "antenna_right": {"id": 2, "center": 2048, "ticks_per_deg": 11.4,
                      "sign": -1, "min": 1024, "max": 3072},
    "body_yaw":      {"id": 3, "center": 2048, "ticks_per_deg": 11.4,
                      "sign": 1, "min": 512, "max": 3584}
  },
  "head": {
    "ids": [4, 5, 6, 7, 8, 9],
    "neutral": [2048, 2048, 2048, 2048, 2048, 2048],
    "presets": {},
    "jacobian": [[0, 0, 0, 0], [0, 0, 0, 0], [0, 0, 0, 0],
                 [0, 0, 0, 0], [0, 0, 0, 0], [0, 0, 0, 0]]
  }
}
```

- `neutral` is the six "level" readings, in ID order 4–9. Each must be between about 1000 and
  3100, or that arm's travel crosses the motor's 4095 → 0 seam.
- Each `center` is read with the part in its middle position; `min`/`max` stay the same distance
  from it as above (antennae ±1024, body ±1536) and inside 0–4095.
- The **all-zero `jacobian` is deliberate**: until the head's limits are captured in Stage 4,
  every head command holds level instead of guessing.
- The head's limits (Stage 4) and the arms' zeros (captured on `/limbs`) are written into the
  same file by the software. None of it can be regenerated — it was measured on that robot —
  which is why the book keeps asking for backups.

**Two traps in the tools, and why the book says "`show` first" so often:**

- Every `calibrate` command **except `show`** opens the motor port and drives the head to
  "home" before doing anything else.
- `calibrate` quietly falls back to built-in defaults when the file is missing or has a typo,
  and the default "home" is 2048 on every head motor — up to about 50° from level on a head with
  its rods fitted. So `show` must say `(loaded)` before anything else runs.

The robot software does the same when it starts: it switches the motors on and drives the head to
level straight away. That's why the autostart isn't installed until Stage 4, step 5, when the
calibration is complete.

---

## The phone

- Plain http is enough for the **eyes and the voice** — no certificate.
- Phones stay silent until tapped, and that permission is lost every time the page reloads, so
  the eyes go amber after a restart until someone taps the face. *Fully Kiosk Browser* (Android)
  can remove the tap and reopen the page when the phone restarts; see
  `hardware/phone-eyes/README.md`.
- The phone's **microphone and camera** need https that the phone trusts (an mkcert certificate
  authority installed on the phone). That isn't part of this build; the top-level `README.md`
  of the main repository covers it.

## The certificate for VR

`scripts/make_cert.sh` (Stage 5) uses `mkcert` if it's installed, and otherwise makes a
self-signed certificate — that's the "Advanced → Proceed" warning. Once a certificate exists the
robot serves **https on 8080 and plain http on 8081**, which is why the phone face has to be
re-added on 8081. To undo it: `rm -r ~/reachy/certs` and `sudo systemctl restart reachy`, and the
phone's old icon on 8080 works again.

### VR head directions

VR steers the real head from the wearer's head, and the three directions are set by
`YAW_SIGN`, `PITCH_SIGN` and `ROLL_SIGN` near the top of `app/static/vr.js`, which the file marks
as not yet checked on hardware. If Stage 5 finds an axis backwards, flip that one constant in the
main repository and rebuild the kit. It's the same code on every robot, so R1's result is
everyone's.

## Updating a robot's software later

Build a new kit, copy the new `reachy-software.tar.gz` into the Pi's home folder, and:

```bash
tar -xzf reachy-software.tar.gz
cd ~/reachy
bash scripts/provision_pi.sh
sudo systemctl restart reachy
```

The archive has no `data/` files and no `.env`, so unpacking it over the old copy leaves the
robot's name, settings and calibration alone.

## What still needs tooling (for whoever picks this up)

- There is no `calibrate capture-neutral`: Stage 3 reads positions with `motor_status.py` and
  the file is edited by hand in `nano`. A command that reads with the head limp — and never
  homes first — would remove the hand edit.
- `calibrate` falls back to defaults on a missing or broken file and then homes to them.
  Refusing to move when the file can't be read would make the `show` ritual unnecessary.
- The arms' mount to the body is a hand-fitted, drilled joint. A printed bracket or a drilling
  template would make six robots match without R1's measurements.

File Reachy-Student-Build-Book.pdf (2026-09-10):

S I X T E A M S · S I X R O B OT S

# Build a Reachy robot

The student build book: print it, set up the motors, build it with the Pi, install the software, test it — then make it yours.

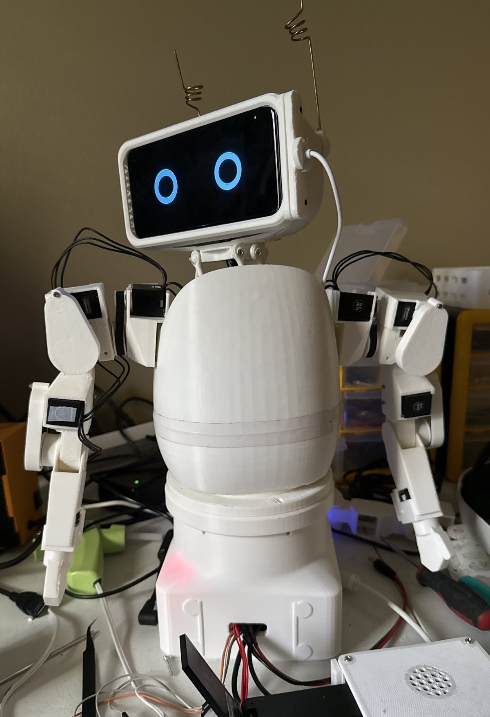
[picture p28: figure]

Start here | What you're building, the six stages, teams, safety, day one
Stage 1 · Print | Test prints first, then every part — arms included
Stage 2 · Motor IDs | Set up the Pi, give all 17 motors their own ID
Stage 3 · Assembly | Head, antennae, face, arms, base and power — with the Pi
Stage 4 · Software | Name, calibration, arms, autostart, the phone face
Stage 5 · Testing | Acceptance test, the Code Lab (Blockly + JavaScript), VR
Stage 6 · Make it yours | Optional: a different phone, voice and eyes
Stage 6 · Your own head | Design your robot's head in Blender
Appendix A | Shopping list
Appendix B | Mentor notes: kit, SD cards, network, power wiring

Reachy student build book | 2 / 56

SSeTpAteRmTbeHrE2R02E6 · generated from docs/student-build/ in the reachy-virtual-robot repository

# Build a Reachy robot — start here

Six teams, six robots. Each team builds a complete Reachy Mini–style robot: a head that nods, tilts and turns on six motors, two springy antennae, two arms, a body that turns on a printed base, a phone for a face, and a Raspberry Pi for a brain. Then you make it yours: its own name, its own voice, and if you like, its own head designed in Blender.

They are copies of Ollie. Everything in this book has been built and broken once already, and the notes are what that taught.

Ollie: the phone face in the head, the wire antennae, both arms fixed to the top of the body, the base that turns, and the Raspberry Pi in its white case beside the base.

Read this | When
This page | Day one: what you're building, the six stages, teams, safety
Stage 1 — Print | Every printed part, test prints first
Stage 2 — Motor IDs | Set up the Pi, give all 17 motors their own ID
Stage 3 — Assembly | Put the robot together, with the Pi beside you
Stage 4 — Software | Name, calibration, arms, autostart, the phone face
Stage 5 — Testing | The acceptance test, the Code Lab (Blockly and JavaScript), VR control

Read this | When
Stage 6 — Make it yours | Optional: a different phone, voice and eyes, your own head in Blender
Appendix A — Shopping list | What to buy, per robot and for six
Appendix B — Mentor notes | Mentors: the kit, SD cards, the network, the power wiring

## What you are building

Part of the robot | What it is | Motors
Head | A 6-motor Stewart platform: six motor arms push six rods that hold up the head. Moving them together makes it nod, tilt, turn and bob | 6 × XL330-M288 (IDs 4–9)
Antennae | Two bent-wire antennae on the back of the head — the robot's main way to show emotion | 2 × XL330-M077 (IDs 1–2)
Arms | Two 4-joint printed arms driven by belts: shoulder pitch, shoulder roll, elbow, wrist | 8 × XL330-M288 (right 14– 17, left 18–21)
Body | The "egg" that holds the head motors. The arms screw to the top of it | —
Base | A printed plinth with a bearing on top; the whole robot turns on it | 1 × XC330-M288 (ID 3)
Face | A Samsung Galaxy S10 behind the face plate. Its screen is the eyes, its speaker is the voice. A cable keeps it charged | —
Brain | A Raspberry Pi 5 beside the base. It runs the robot's software and talks to the motors through a USB adapter (the U2D2) | —

Seventeen motors on one cable. Every motor is daisy-chained on a single bus, and every motor has an ID number. The ID is how the software knows which motor is which, so setting the IDs is the first thing you do with the motors (Stage 2).

The Pi is your workbench computer. From Stage 2 on, every command in this book is typed on your robot's own Pi, with a monitor, keyboard and mouse plugged into it. You don't need a laptop. The only other computer you'll use is for Blender, if you design a head in Stage 6.

The six stages

Stage | What | Who | You're done when
1 · Print | Test prints, then every part | Print lead | Every part is printed, checked and labelled
2 · Motor IDs | Set up the Pi; give each motor its ID | Motors lead + software lead + mentor | A scan finds all 17 motors
3 · Assembly | Head, antennae, face, arms, base, power | Mechanical lead + motors lead + mentor | The robot is built and its head's "level" is recorded

Stage | What | Who | You're done when
4 · Software | Name, calibration, arms, autostart, phone | Software lead + mentor | The robot starts by itself, calibrated
5 · Testing | Acceptance test, Code Lab, VR | Whole team | Every box on the checklist is ticked
6 · Make it yours | Optional: phone, voice, eyes, your own head | Designer + everyone | Whenever you like

Every stage ends in a ✅ checkpoint. Don't start the next stage until your robot passes it, and don't start a stage at all until the pilot robot (R1) has passed it. Where a step says mentor, a mentor is at the table for it.

## How six teams build six robots

Every robot has a number, R1 to R6, for its whole life. Put it on everything: printed parts (pencil or marker on a hidden face), motors (painter's tape), cables, the SD card, the phone, the USB stick, the parts bin. Six robots' worth of identical parts on one table is how a calibrated part ends up in the wrong robot.

R1 is the pilot robot. One team runs each stage a few days ahead of everyone else. The other five start a stage only after R1 has passed its checkpoint. A problem gets found once, not six times. The same goes for printing: print one of anything new, check it, then print five more.

Parts that belong to one robot never move to another. Motors (their IDs and positions are recorded), rods, motor arms, the calibration file and the phone all get matched to one robot. Swapping a calibrated part is how the robot on the next table starts moving wrong.

Roles on a team (4–5 people)

Role | Owns
Print lead | The team's print queue, slicer settings, labelling printed parts
Motors & wiring lead | Motor IDs, cables, the bus, strain relief, the power checks
Mechanical lead | Rods, motor arms, the head and neck, the arms and belts, the base
Software lead | The Pi, the phone, the robot's name and voice (with the mentor)
Designer | Optional: the robot's own head in Blender (everyone can help)

Everyone owns safety.

## Safety — non-negotiable

1. The motors are 5-volt parts. The robot's power brick is 12 V, and a converter turns that into 5 V for the motors. 12 V on the motor bus destroys every motor at once. Only a mentor wires or changes the power parts, and the 5 V is measured with a meter before any motor is connected.

2. Power off before you plug or unplug any motor cable. Hot-plugging is how a motor gets a wrong ID or drops off the bus.
3. Keep fingers out of the neck and the belts while the motors are powered. Six motor arms and six rods make a pinch point, and so does every belt. Before you move the head or an arm by hand, it must be limp (torque off).
4. An arm falls when it goes limp. Hold it, or make sure nothing is under it, before you switch the motors off or press PANIC.
5. Soldering only with a mentor present. Eye protection, ventilation, iron in its stand.
6. Hot water for the ball joints (80–90 °C) — tongs or gloves, mentor present.
7. Phones: never put a phone with a swollen battery into the head. The phone charges inside the head, so check its back is still flat every time the head is opened.
8. Printers: don't touch the nozzle or the bed. PETG needs ventilation.
9. VR: the person in the headset can't see the real robot. Someone else always watches the robot, with a hand near the power switch.
10. Children will touch this robot. Nothing sharp: round every point and edge, including the ends of the antenna wire.

## Day one

1. Form six teams, give each a robot number (R1 = the pilot team) and assign roles.
2. Safety briefing — the list above, out loud.
3. Start printing the test pieces (Stage 1). They answer "will it fit?" before anyone commits a ten-hour print.
Also start the long, safe prints: body_top , body_down , head_back , base_body .
4. Inventory what has arrived against the shopping list. Label boxes R1–R6.
5. Software leads: set up your Pi (Stage 2, step 1). It can happen while the printers run.
6. Designers: if your team wants its own head, install Blender and sketch the character on paper first (Blender). Design runs alongside the build.

## Where the files are

Everything to print, and this book, is in the ollie-3d repository. Your team also gets a USB stick from the mentor with the same files plus the robot software:

Folder | What's in it | Where
print/ | Every part for one robot, grouped in printing order. All millimetres — print at 100 %. PRINT_LIST.csv says how many of each and how to lay it on the bed | ollie-3d and the USB stick
blender/ | The Blender starter file and its check script (Stage 6) | ollie-3d and the USB stick
Reachy-Student-Build-Book.pdf | This book, ready to print | ollie-3d and the USB stick
software/ | reachy-software.tar.gz — the robot software, installed onto the Pi in Stage 2 | USB stick only

Keep the stick: it's also where your robot's calibration file is backed up.

Credits. The stock Reachy Mini parts — the head back, crown cover, neck and Stewart plates, antenna parts and body shells — are Pollen Robotics' designs, converted here to millimetres. Everything else was designed for Ollie.

S TAG E 1 · PRI N T

# Stage 1 — Print everything

Everything gets printed before anything gets built. Printing takes days and the build takes hours, and a part that doesn't fit is far cheaper to find now than halfway through the assembly. The print lead owns this stage; everyone else can help sort, clean up and label parts as they come off the printer.

Use the files in the print/ folder — in the ollie-3d repository, or on your team's USB stick. They are already in millimetres and already turned the right way up, so print everything at 100 %, and don't rotate the arm parts. (If you take a file straight from the robot's main repository instead: the stock Reachy parts in hardware/oem/ are modelled in metres and import 1000× too small.)

Default settings unless a row says otherwise: PETG, 0.2 mm layers, 3 walls, 15–20 % infill.

## 1. Test prints — before anything else

Each of these is small and answers one question that would otherwise cost a big print. R1 prints them first; the other teams print them once R1's have passed. Write every result in the team log.

Print | File | Question it answers | Pass when
Hug test | eye_hug_test.stl | How much grip does your printer and plastic give a ball joint? | A ball pressed into the longest-stub eye can't be pulled off by hand
Balls | balls_production_9.05_x6.stl | Are the balls the right size? | Calipers read 9.00–9.10 mm. At 8.95 the joint holds half as well
One rod | rod_v6_eye_rod_122mm.stl | Does the snap ring hold a ball? | Ball swaged in warm (Stage 3), swivels freely, won't pull out
One motor arm | arm_30mm.stl | Does the arm fit the motor and the rod? | Sits flat on the motor's round boss, 4 × M2 screws bite, the rod bolts on
Yaw clamp | yaw_clamp.stl | Does the base's hardest joint fit the body-turn motor? | Its nose seats on the XC330's boss with no rocking. Print it nose up
Face plate | s10_face_plate.stl + s10_face_cap.stl | Does your S10 fit? | Test it the way it goes in the head — charging port at the service-cap end, cable plugged in. The phone slides in with a firm push at the end, the cap screws shut over the cable, nothing rattles or rocks
Arm joint coupon | coupon_joints.stl | Do the arm's two printed-in-place joints come out loose enough to turn? | After breaking them loose by hand, both joints turn with a fingertip. This is the most important test print — the first arm came off the bed with its elbow welded solid

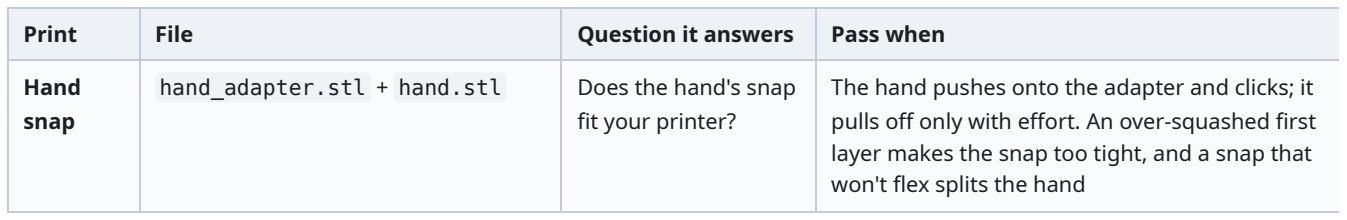
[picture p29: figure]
Print; File; Question it answers; Pass when

Hand snap | hand_adapter.stl + hand.stl | Does the hand's snap fit your printer? | The hand pushes onto the adapter and clicks; it pulls off only with effort. An over-squashed first layer makes the snap too tight, and a snap that won't flex splits the hand

If a test fails, stop and tell the mentor before printing the real parts. A fit is the one thing only your printer can answer.

## 2. Print list — one robot

print/PRINT_LIST.csv is the same list, with a done column to tick off.

Head and neck

Part | File | Qty | Notes
Head back | head_back.stl | 1 | Supports under the openings
Crown cover | head_mic.stl | 1 | Easy to forget — without it the top of the head is an open slot
Face plate | s10_face_plate.stl | 1 | Face down on the bed, no supports. Sized for a Galaxy S10 only
Service cap | s10_face_cap.stl | 1 | Tongue side down, no supports
Neck plate | neck_reference.stl | 1 | 20 % infill. Its six numbered holes take the rod tops
Stewart main plate | stewart_main_plate.stl | 1 | 20 % infill
Stewart tricap | stewart_tricap.stl | 1 | 20 % infill
Rods | rod_v6_eye_rod_122mm.stl | 6 (+2 spare) | 0.15 mm layers, no supports, lying flat, 4 walls, 40 %+ infill. It must be the v6_eye file — see below
Balls | balls_production_9.05_x6.stl | 2 plates (12 balls) | As oriented (bore down), 0.10–0.15 mm layers. Print a third plate for spares
Motor arms | arm_30mm.stl | 6 (+2 spare) | Flat, 4 walls, 50 %+ infill — these carry full motor torque

⚠️ The rod file is rod_v6_eye_rod_122mm.stl and nothing else. The robot's main repository also holds older lengths and other joint styles, and one of them has been printed by mistake before. The right one has a raised collar around the ball hole on both faces.

Antennae

Part | File | Qty | Notes
Antenna hub | antenna_body.stl | 2 | One per antenna
Antenna interface | antenna_interface.stl | 2 | One per antenna
Motor holder, left | antenna_holder_l.stl | 1 | 20 % infill
Motor holder, right | antenna_holder_r.stl | 1 | 20 % infill

The antennae themselves aren't printed: they're stiff wire, bent by hand in Stage 3.

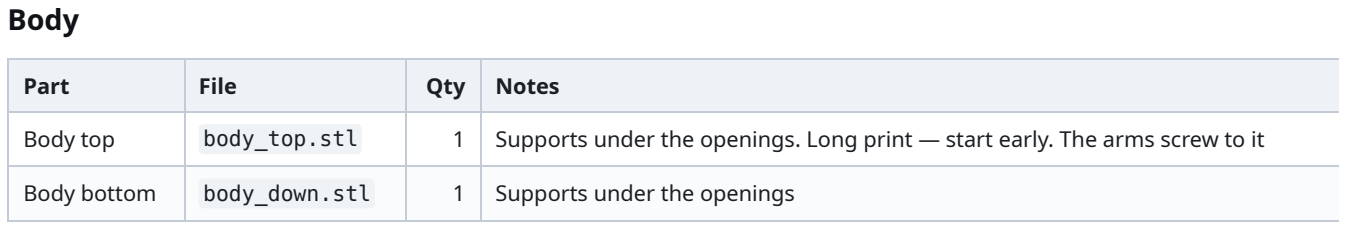
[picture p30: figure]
Body; Part; File; Qty; Notes; Body bottom; body_down.stl; Supports under the openings

Body top | body_top.stl | 1 | Supports under the openings. Long print — start early. The arms screw to it

Base, yaw joint and Pi case

Part | File | Qty | Notes
Plinth | base_body.stl | 1 | About ten hours. Upright, no supports, 20 % infill. Turn on bridge detection (the window ceiling is a 62 mm bridge)
Stator (cap) | base_top.stl | 1 | Flat, upright, no supports, 25–30 % infill — carries the robot
Rotor | yaw_rotor.stl | 1 | Flat, upright, no supports, 25–30 % infill
Clamp / drive hub | yaw_clamp.stl | 1 | Print it NOSE UP — flat on the bed puts the nose under the bed. Keep your test print if it passed
U2D2 tray | u2d2_tray.stl | 1 | No supports
Shelf (optional) | base_shelf.stl | 1 | Disc down, legs up, no supports
Pi case tray | pi5_tray.stl | 1 | As it loads, no supports, 20 %
Pi case cover | pi5_cover.stl | 1 | Upside down — roof flat on the bed

Arms — both arms

Every arm file in the kit is already the right way up. The two arm_printed parts are the exception to every other habit you have: don't rotate them on the bed, because their joints are printed in place and the gaps in them are sized for exactly that orientation.

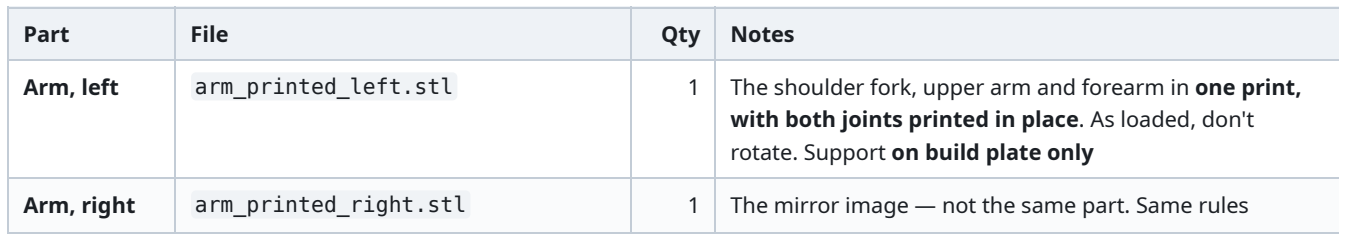
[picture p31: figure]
Part; File; Qty; Notes

Arm, left | arm_printed_left.stl | 1 | The shoulder fork, upper arm and forearm in one print, with both joints printed in place. As loaded, don't rotate. Support on build plate only
Arm, right | arm_printed_right.stl | 1 | The mirror image — not the same part. Same rules

Part | File | Qty | Notes
Shoulder housing | shoulder_housing.stl | 2 | As loaded, don't rotate. It screws to the body
Hand | hand.stl | 2 | Serves both arms
Hand adapter | hand_adapter.stl | 2 | The hand snaps onto it
Wrist clamp | wrist_clamp.stl | 2 | Holds the wrist motor in its cradle
Boss adapter | boss_adapter.stl | 6 | Printed on its side, as loaded
Small pulley, 20 teeth | pulley_20t.stl | 6 | On each belted motor
Big pulley, 40 teeth | pulley_40t_flange.stl | 6 | On each joint
Roll belt cover, left | belt_cover_roll_left.stl | 1 | Flat, no supports
Roll belt cover, right | belt_cover_roll_right.stl | 1 | Flat, no supports. The mirror of the left
Elbow belt cover | belt_cover_elbow.stl | 2 | Flat, no supports. Serves both arms
Bushing | bushing.stl | 4 | Two per shoulder housing
Pitch shaft | shaft_pitch_44mm.stl | 2 | Lying down — stood up, it snaps along its layers
Shaft collars | collar_2mm.stl , collar_3mm.stl , collar_4mm.stl | 2 each | Shims for the pitch shaft. Print all three sizes; Stage 3 uses whichever fits

Three rules for the two arm_printed parts, all learned from arms that came off the bed stuck:

Support on build plate only. A slicer allowed to support everywhere will try to fill the 0.4–0.7 mm gaps inside the joints, and a joint with support inside it never moves.
If the slicer offers to "repair", "merge" or "make solid", say no. Each file is six separate pieces on purpose — the gaps between them are the joints.
Don't over-squash the first layer. It eats the joint's clearance on its own.

Weigh the first arm_printed as it comes off: about 62 g. If it's far off that, tell the mentor — the arm's strength numbers assume it.

Do not print

head_front.stl — replaced by the S10 face plate.
body_foot.stl and body_turning.stl — replaced by the printed base and yaw joint.
pitch_fork.stl , upper_arm.stl , forearm.stl — these are the arm's parts drawn separately for the 3D preview. They can never be joined; arm_printed is the file.
shoulder_spine.stl — it ties the two shoulders together for an arm built on its own. On this robot the shoulders screw straight to the body shell instead.

Anything in the main repository's hardware/oem/reference/ — those are models of parts you buy.

None of these are in print/ , which is the easiest way to avoid printing them.

How much plastic

One robot is about 1.5 litres of solid plastic — 1.2 litres for the head, body and base and 0.35 for the two arms (measured off the files). At the infills above that prints at roughly 1.3 kg of PETG per robot. Test pieces, spares and reprints add about half as much again, so order about 12 kg of PETG for six robots.

## 3. Label everything

As each part comes off the printer: clean off supports and brims, then write the robot number on a hidden face in pencil or marker, and put it in the robot's bin. Left and right parts go in separate bags marked L and R — the left and right arm parts look alike and are not the same.

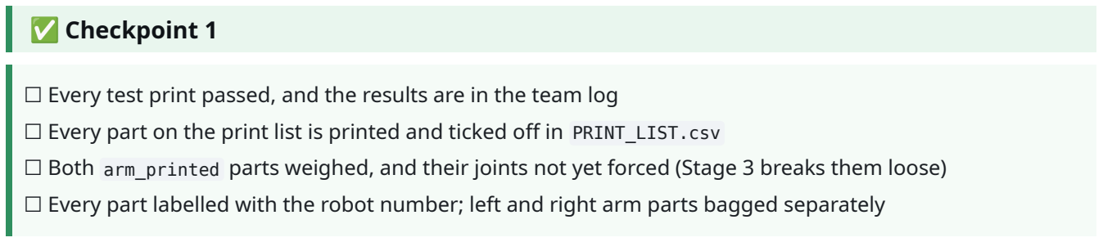
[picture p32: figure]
✅ Checkpoint 1

☐ Every test print passed, and the results are in the team log
☐ Every part on the print list is printed and ticked off in PRINT_LIST.csv
☐ Both arm_printed parts weighed, and their joints not yet forced (Stage 3 breaks them loose) ☐ Every part labelled with the robot number; left and right arm parts bagged separately

S TAG E 2 · M OTO R I D S

# Stage 2 — Motor IDs

Every DYNAMIXEL motor leaves the factory as ID 1 at 57600 baud. Seventeen motors all answering to "1" on one cable just talk over each other, so each motor gets its own ID before they are chained together — one motor at a time, with nothing mechanical attached. The tool that does it runs on your robot's Pi, so the Pi is set up first.

## 1. Set up the Pi — your workbench computer

Software lead, with the mentor. This can happen on day one while Stage 1 prints.

You need: the Raspberry Pi 5 and its official 27 W power supply, the Active Cooler, the SD card the mentor prepared for your robot, a monitor and a micro-HDMI cable, a USB keyboard and mouse, your team's USB stick, and the school wifi (the install downloads packages).

1. Press the Active Cooler onto the Pi (its two push-pins go into the holes beside the processor) and plug its fan lead into the socket marked FAN.
2. SD card in, then monitor (the HDMI port nearest the power socket), keyboard and mouse, and power last. The Pi starts to the desktop.
3. Connect to the wifi from the network icon at the top right, if the mentor hasn't already.
4. Plug in the USB stick. In the file manager, copy software/reachy-software.tar.gz from the stick into your home folder.

### 5. Open a Terminal (the black icon on the top bar) and install the software:

tar -xzf reachy-software.tar.gz
cd ~/reachy
bash scripts/provision_pi.sh

It takes several minutes and ends with Done. It installs the robot software, the motor tools, and the permission to use the motor adapter.
6. Restart the Pi ( sudo reboot ). That permission only takes effect after a restart.

From here on, every command in this book is typed in a Terminal on the Pi, starting in the reachy folder. A new Terminal starts in your home folder, so type cd ~/reachy first.

## 2. Motor power on the bench (mentor)

The motors take 5 V from the U2D2 Power Hub. On this robot the Power Hub is fed by a converter that turns the 12 V power brick into 5 V (Appendix B says how the mentor wires it).

1. Mentor: with no motor plugged in, switch on and measure the Power Hub's input with a meter. It must read about 5.0 V (4.9–5.1). If it reads 12, stop: something is wired wrong, and 12 V destroys every motor it reaches.
2. Switch the Power Hub off. Plug the U2D2 into one of the Pi's USB ports, and connect the U2D2 to the Power Hub with the short 3-pin cable.

## 3. The ID map — the same on every robot

ID | Motor | Model number the scripts print | Where it goes
1 | XL330-M077 | 1190 | Left antenna (the robot's own left)
2 | XL330-M077 | 1190 | Right antenna
3 XC330-M288 (metal | case) | 1240 Body turn, in the base
4–9 | XL330-M288 | 1200 | The six head motors
14 | XL330-M288 | 1200 | Right arm — shoulder pitch (in the shoulder housing)
15 | XL330-M288 | 1200 | Right arm — shoulder roll (on the fork, above the shoulder)
16 | XL330-M288 | 1200 | Right arm — elbow (lying flat in the upper arm)
17 | XL330-M288 | 1200 | Right arm — wrist (in the forearm)
18– 21 | XL330-M288 | 1200 | Left arm — the same order: pitch, roll, elbow, wrist

All seventeen run at 1 Mbps (1 000 000 baud). IDs 10–13 are not used. The software expects exactly this map.

The arm order matters. The software reads the first ID of each arm as the shoulder pitch, the next as the roll, and so on. On Ollie two shoulder motors went in the wrong places, and the pitch slider moved the roll joint. Labelling every motor with its job now is what prevents that.

The head and the arms use the same motor, the XL330-M288. The two antenna motors (M077) look identical but are weaker and faster, and the body-turn motor is the one with the metal case. Check the model number the script prints every time.

## 4. Give each motor its ID

1. Power Hub off. Plug one motor into the Power Hub. Switch on — the motor's LED blinks once.

### 2. Give it its ID and the fast baud rate. For a head motor that will be ID 4:

cd ~/reachy
.venv/bin/python scripts/set_id.py --new-id 4 --new-baud 1000000

The script refuses if it sees more than one motor, which is the point. It prints the motor's model number — check it against the table.
3. Power off. Stick a tape label on the motor with robot, ID and job: R3 · 4 · head , R3 · 14 · R shoulder
pitch , R3 · 21 · L wrist . Unplug it.
4. Repeat for all seventeen: the two M077 motors (1190) get IDs 1 and 2, the XC330 (1240) gets ID 3, six M288 get 4–9, and eight M288 get 14–21.

## 5. All together, and a health check

5. Chain all seventeen together in any order (power off while you plug), switch on, and scan:

.venv/bin/python scripts/scan_dynamixel.py

You should see exactly seventeen motors at 1000000: 1–2 = XL330-M077, 3 = XC330-M288, 4–9 and 14–21 = XL330-M288. Count them. Two motors accidentally given the same ID look exactly like one working motor, and nothing else will tell you.

### 6. Does every motor actually reach where it's told?

.venv/bin/python scripts/nudge_diag.py --ids 1,2,3,4,5,6,7,8,9,14,15,16,17,18,19,20,21 .venv/bin/python scripts/motor_status.py

nudge_diag moves each motor a few degrees each way and reads it back. A motor whose position doesn't change while it draws only a little current has a broken gear — the motor spins but the output doesn't; Ollie had one straight out of the box. (A lot of current and no movement means something is blocking it.) motor_status should show no hardware error, about 5 V, and room temperature on every motor.

✅ Checkpoint 2

☐ The Pi starts to the desktop, and cd ~/reachy works in a Terminal
☐ 5 V measured at the Power Hub before any motor was connected
☐ The scan shows exactly 17 motors — 1–9 and 14–21 — all at 1000000, the right model on each ID
☐ nudge_diag shows every motor reaching its targets in both directions
☐ Every motor labelled with robot number, ID and job

If a motor won't show up: power the motors off and on (a motor that stalled can go silent until its power is cycled), reseat its cable, try it alone, try scan_dynamixel.py --all-bauds . If its LED lights but it never answers, check the cable is in a 3-pin TTL port on the hub. Trust the ID the scan reports over the sticker — stickers get shuffled.

S TAG E 3 · AS S E M BLY

# Stage 3 — Assembly

The Pi stays on the bench beside you for this whole stage, with its monitor and keyboard, the U2D2 plugged in, and the motors on the Power Hub. The head's motor arms are fitted while the Pi tells you exactly where each motor is, and the head's "level" is recorded on the Pi.

The stock Reachy parts (the motor cages, the neck, the body) go together as the official Reachy Mini assembly guide (https://huggingface.co/spaces/pollen-robotics/Reachy_Mini_Assembly_Guide) shows. This chapter says where our robot is different, what order to work in, and what has gone wrong before.

Step | What | Who
1 | Rods, balls and motor arms | Mechanical lead
2 | Head motors and neck, and recording "level" | Mechanical lead + mentor
3 | Antennae | Mechanical + motors
4 | The face plate | Mechanical lead
5 | The arms | Mechanical lead
6 | The arms onto the body | Mechanical lead + mentor
7 | The base and the yaw joint | Mechanical lead
8 | Power and cables | Motors lead + mentor

One program on the motors at a time. Nothing stops two programs driving the motors at once, and they fight. Run one motor command at a time, and never while the robot software is running in another Terminal.

## 1. Rods, balls and motor arms

The head hangs on six rods. Each rod has a ball joint at both ends: a printed ball snapped into a ring in the rod. Twelve balls for six rods.

Check before you start. It must be rod_v6_eye_rod_122mm.stl — there is a raised collar around the ball hole on both faces. And measure every ball with calipers: 9.00–9.10 mm. A ball printed small holds half as well; a ball printed big never seats. Sort out any that are off.

Swage the balls in (mentor — hot water)

The ball is a tight fit on purpose — that tightness is what keeps the rod on the head.

1. Heat water to 80–90 °C (PETG needs the lower end).
2. Hold the rod's eye in the water for about 20 seconds (tongs).
3. Push the ball through the ring — it goes in with a firm squeeze, not a click.

4. Work the joint round in every direction while it cools, so the ring sets to the ball's shape instead of just gripping it.

Push each ball in once. Every time a ball is pulled out and pushed back the ring stretches a little. If a rod feels loose, print a new rod.

Motor arms

Clean the four small holes and the tip hole with a drill bit turned by hand. Test-fit an M3 × 18 through the tip hole and an M3 nut into its pocket on the back. Don't screw the arms onto the motors yet — step 2 says how, and the angle matters.

✅ Checkpoint 3.1

☐ 6 rods (+ spares), each with both balls swaged in, swivelling freely, can't be pulled off ☐ 6 motor arms, holes cleaned, nut fits its pocket

## 2. The head motors and neck

Build the six head motors (IDs 4–9) into their cages following the official guide. What is different on our robot:

Official guide | Our robot
Metal link rods | Printed rod_v6 rods, 122 mm between ball centres
Stock motor arms | Printed arm_30mm arms, 4 × M2 × 5 self-tapping into the motor's round boss
Camera, lens and speaker in the head | Not fitted — the phone does all three
head_front | Replaced by the S10 face plate (step 4)

The six head motors sit in three pairs around the centre, facing inward: each motor's round output boss points at the centre column, so its arm swings in an upright plane beside the motor. At the resting pose every arm is level, the two arms of a pair point away from each other, and the rod's ball sits on the arm's inner face. Match the picture in the official guide before you tighten anything.

Which motor goes where. The software doesn't care which cage holds which ID, but all six robots use the same layout so they can be compared: ID 4 drives the rod into neck hole 1, ID 5 into hole 2 … ID 9 into hole 6 (the neck plate's holes are numbered). Write it in the team log.

Fitting the arms — where "level" lands matters (mentor)

A motor reports its angle as a number from 0 to 4095, and the number jumps from 4095 back to 0 at one point in the turn (the seam). If an arm's level position lands near the seam, the software thinks the arm has spun right round when it crosses it. That happened on Ollie and cost an arm removal to fix. So:

1. Motors in their cages, no motor arms fitted, the Power Hub on.

### 2. Send every motor to the middle of its range (2048):

cd ~/reachy
.venv/bin/python -m scripts.calibrate show .venv/bin/python -m scripts.calibrate home .venv/bin/python -m scripts.calibrate home
.venv/bin/python scripts/motor_status.py --ids 4,5,6,7,8,9

show must print a path ending in reachy/data/motor_calibration.json , then (defaults) — and a warning
that the file is unusable. That's expected here: your robot has no calibration file yet, and that is what makes "home" mean 2048. home runs twice because a long move can be cut short when the script lets go. Afterwards motor_status should read about 2048 (±20) on every head motor. The motors go limp but stay where they were sent.

⚠️ show first, every time. It is the only calibrate command that moves nothing — every other one switches the motors on and drives them to "home" straight away.

3. Without turning the motor, fit its arm in whichever of the four bolt positions is closest to level, pointing away from its pair partner. It won't be exactly level — the bolt pattern only goes on in quarter turns — and that's fine.
4. Screw it down with 4 × M2 × 5 (small screws in plastic — snug, not tight).

Record "level" — before any rod goes on (mentor)

This is the moment it's easy: six loose arms and a spirit level. With the rods on, the arms can't be set level one at a time.

1. Hold each head motor's arm level — a small spirit level, or a phone level app laid along the arm. The motors are limp; the arms stay where you put them.

### 2. Read all six:

.venv/bin/python scripts/motor_status.py --ids 4,5,6,7,8,9

Write the six positions ( pos ) in the team log, in ID order.
3. Each must be between about 1000 and 3100. Closer to 0 or 4095 than that and the arm's travel crosses the seam — take that arm off, move it one bolt position, and read it again.

### 4. Make your robot's calibration file from the template and put your numbers in it:

mkdir -p data
cp calibration-template.json data/motor_calibration.json
nano data/motor_calibration.json

Replace the six 2048 s after "neutral" with your six readings, in ID order 4–9. Leave everything else alone. Ctrl-O then Enter saves; Ctrl-X exits.

### 5. Prove the file reads:

.venv/bin/python -m scripts.calibrate show

It must say (loaded) and show your six numbers.
6. Copy data/motor_calibration.json onto the USB stick as calibration-R3.json (your robot's number). It
was measured on this robot and can't be made again.

From here on, "home" sends the head to level instead of 2048 — which is what makes it safe to run with the rods fitted. show must say (loaded) before any home . If it ever says (defaults) — a typo in the file, a missing comma — stop: with the rods on, 2048 binds the head. (Appendix B explains the rest of the file.)

Rods

Each rod: an M3 × 18 goes through the bottom ball into the motor arm's tip, with the nut in the pocket behind. An M3 through the top ball fixes it into its numbered hole under the neck plate.

⚠️ The one screw rule that matters. Tighten until the ball has no wobble, then back off a hair until it swivels freely under finger pressure. A clamped ball joint makes the head stiff and stops it reaching its angles — on Ollie, over-tight neck screws were most of why the head "couldn't get its range".

Cables

The six head motors are daisy-chained. Hot-glue or zip-tie every connector so the head's movement can't pull one half out. On Ollie, a motor dropping off the bus when a cable was nudged was a regular fault until every connector had strain relief.

✅ Checkpoint 3.2

☐ calibrate show says (loaded) with your six level readings, all between 1000 and 3100
☐ The calibration file is backed up on the USB stick
☐ With the motors unpowered, the head moves by hand through nod, tilt and turn with no binding or clicking, and no rod pops off
☐ Every rod-top screw passes the "swivels freely" test
☐ A scan still finds all six head motors (the cables survived)

## 3. Antennae

The two antenna motors (M077, IDs 1 and 2) sit in the printed holders inside the back of the head, shafts pointing backwards. The hub goes on the motor and the wire goes in the hub.

1. Build each antenna motor into its holder (left and right holders are different parts).
2. Plug in one antenna motor (power off), then scan. It must appear alongside the others. On Ollie, plugging the antennae in once killed the whole bus — every motor went silent — and the cause was never found. One at a time tells you immediately which one it is.
3. Send it to the middle of its range: calibrate show — must say (loaded) — then calibrate home twice.

4. Make the antenna: stiff wire (brass or steel), bent by hand with a small coil a little above the hub — the coil is what makes it bounce. Ollie's are in the photo on the first page. Measure the hole in the antenna hub and pick wire that is a snug push fit; make it about the height of Ollie's (the stock antenna is about 165 mm). Round off the top end with a file or a blob of hot glue — children will touch it.
5. Fit the hub, and push the wire in so it points straight up. That keeps the antenna's swing clear of the motor's seam.
6. Repeat for the other antenna, then strain-relieve both cables.

### 7. Record the antennae's centre: with both wires pointing straight up, read them:

.venv/bin/python scripts/motor_status.py --ids 1,2

Open data/motor_calibration.json in nano again and put the two readings in as the center of antenna_left (ID 1) and antenna_right (ID 2). Set each one's min to its centre minus 1024 and max to its centre plus 1024. Save, run calibrate show (must say (loaded) ), and copy the file to the USB stick again.

Nothing may sit in the antennae's path: they swing through a band across the top and back of the head.

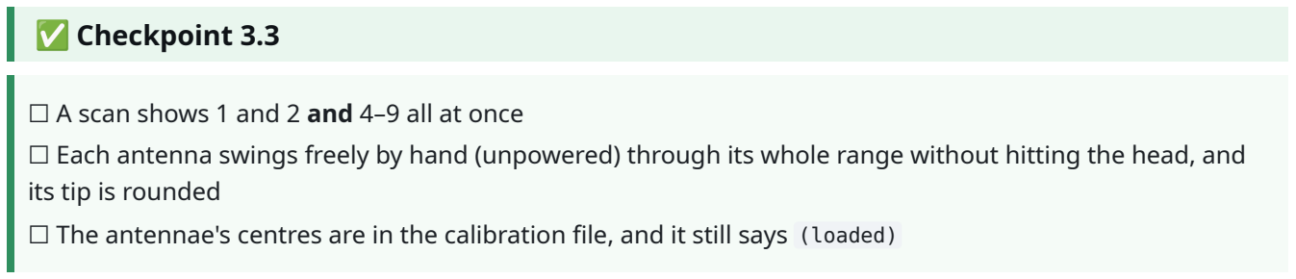
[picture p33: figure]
✅ Checkpoint 3.3; its tip is rounded

☐ A scan shows 1 and 2 and 4–9 all at once
☐ Each antenna swings freely by hand (unpowered) through its whole range without hitting the head, and

☐ The antennae's centres are in the calibration file, and it still says (loaded)

## 4. The face plate

The face is a Samsung Galaxy S10 mounted sideways behind the face plate. Its screen draws the eyes and its speaker is the voice. The plate goes on now; the phone goes in during Stage 4, once it has been set up and paired — it slides in from the side, so the head doesn't have to come apart for it.

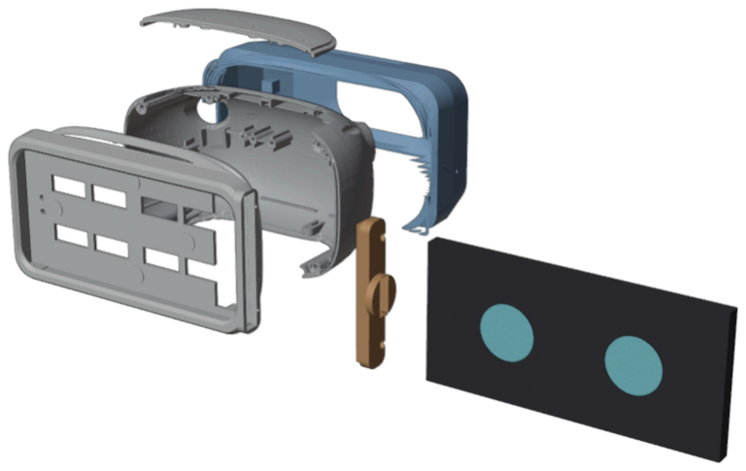
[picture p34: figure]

The head, pulled apart: the stock head back (grey) with the crown cover above it, the S10 face plate (white) in front, the service cap (orange) and the phone beside it — it slides in sideways — and a back shell (blue) behind. The back shell is only needed for a head designed in Stage 6.

1. Offer the face plate up to head_back the way the original face went on: tabs into the six slots, the locating nubs register, then the original four screws in from the back.
2. Clip head_mic into the slot across the crown.
3. Keep the service cap and its two M2 × 10 screws in the bin until Stage 4.
4. Plan the phone's charging cable now. Ollie's phone stays plugged in: a USB-C cable leaves the head beside the service cap and runs down behind the head into the body (you can see it in the photo on the first page). It needs enough slack for the head to nod, tilt and turn the whole way, and it must be tied where it can't catch in the neck rods. It ends at the phone's USB charger in the base (step 8).

⚠️ Weight. The phone is 157 g on the front of a head held up by six small motors. Don't add anything to the head that isn't in the design.

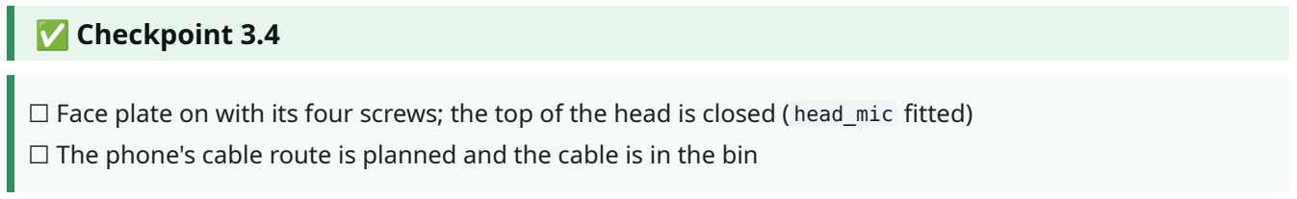
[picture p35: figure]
✅ Checkpoint 3.4

☐ Face plate on with its four screws; the top of the head is closed ( head_mic fitted) ☐ The phone's cable route is planned and the cable is in the bin

## 5. The arms

Each arm has four motors: shoulder pitch (swings the arm forward and back), shoulder roll (lifts it out to the side), elbow, and wrist. The first three drive their joints through belts at 2:1; the wrist drives the hand directly.

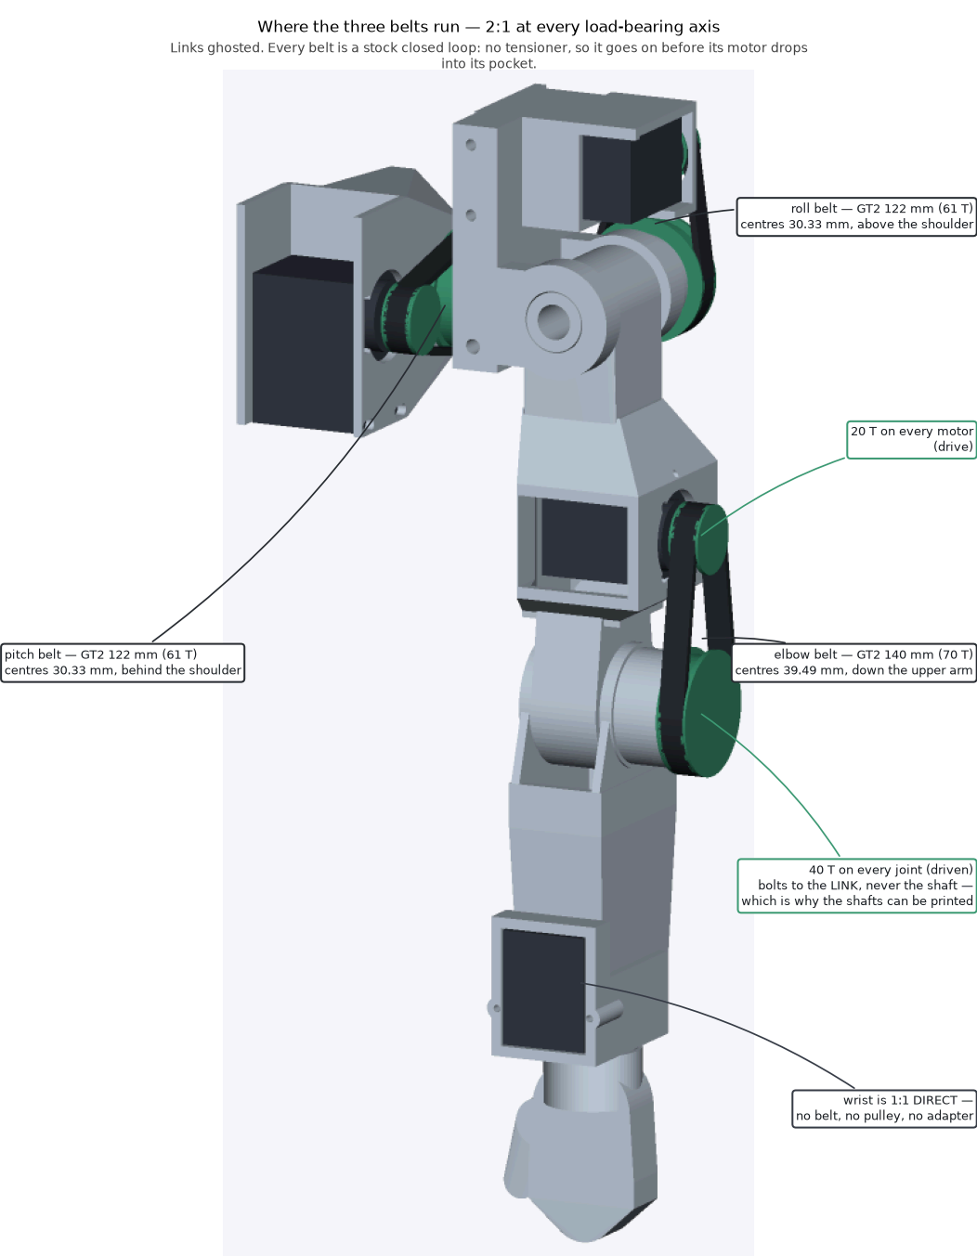
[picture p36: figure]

One arm, with the belts shown: the pitch belt behind the shoulder, the roll belt above it, the elbow belt down the upper arm. Every belt is a closed loop with no tensioner, so it goes on before its motor goes into its pocket.

Before you start:

Sort the parts into two piles, left and right. arm_printed , the roll belt cover and the motors (14–17 right, 18–21 left) are different for each side. On a finished arm, whichever side it is, the elbow belt runs down the outboard face of the upper arm, and the roll pulley faces forward. If your dry fit puts them the other way, you have the other arm's part.

Which motor goes where — check the labels from Stage 2 as each one goes in:

Joint | Right arm | Left arm | Where it sits
Shoulder pitch | 14 | 18 | In the shoulder housing
Shoulder roll | 15 | 19 | On the fork, above the shoulder
Elbow | 16 | 20 | Lying flat in the upper arm
Wrist | 17 | 21 | In the forearm's cradle

The belts (per arm): two 122 mm GT2 loops (pitch and roll — the same belt, so nothing to mix up) and one 140 mm loop (elbow), all 6 mm wide.

No need to position the arm motors first. Unlike the head, the arm's zero is recorded after the arm is built (Stage 4), so the motors can be at any angle when the belts go on.

Work from the hand inward. A closed belt has no slack, so each one is looped over both its pulleys while the motor is loose in your hand, and only then does the motor slide into its pocket. Every step below keeps the screwdriver's path open for the next.

Step 1 — Break the printed joints loose

The arm_printed part came off the printer with its elbow and shoulder joints already made. Straight off the bed the gaps may be lightly stuck together. Work the elbow first, gripping the forearm close to the joint — a long lever on a stuck joint snaps a 3 mm cheek off instead of freeing it, and that is exactly how the first arm was lost. Then work the shoulder. Both should turn by fingertip. If either won't move at all, stop and tell the mentor — don't force it.

Step 2 — Bushings and the pitch pulley
1. Press the two bushings into the shoulder housing, one from each end face of its bearing barrel. Press them square in a vice with a flat plate. Test the first one: it should need a firm push and then stay put, and the printed shaft should turn freely in it afterwards.
2. Bolt the pitch 40-tooth pulley onto the fork now — its inboard face (the side that will face the body), 3 × M2 × 16 straight into the printed hub. Once the arm is in the housing those screws can't be reached. Snug, not tight: you're cutting a thread in plastic. The pulley's flange must sit flat on the hub face with no gap.
Step 3 — Drive stacks (pitch, roll and elbow motors)

For each of the three belted motors, in your hand:

1. boss_adapter over the motor's round boss, 4 × M2 × 5 countersunk. Each head ends up flush or just below the plate's top face. Snug only.
2. pulley_20t drops onto the adapter's four drive pins.
3. One M2 × 8 down the centre. Its head sits at the bottom of the pulley's socket, not flush at the top — the space above it is where a belt cover's pin goes.

Spin it and watch the flange: any wobble means the adapter isn't seated on the boss.

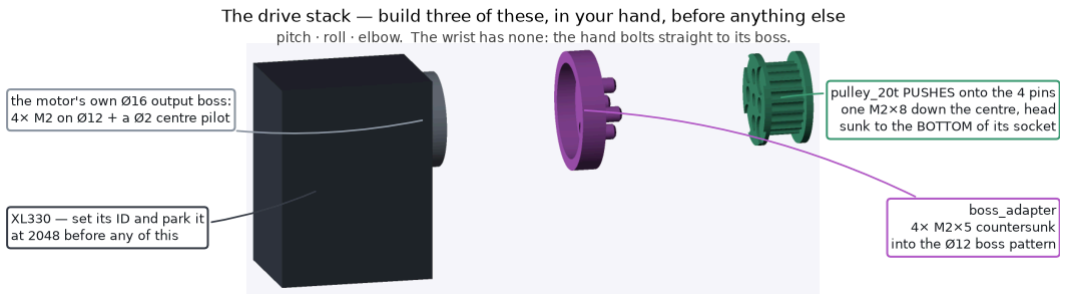
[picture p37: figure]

The drive stack: motor, boss adapter, 20-tooth pulley, centre screw.

Step 4 — Hand and wrist
1. Drop the wrist motor (17 / 21) into the forearm's cradle from the back, and bolt the wrist_clamp across the opening with 2 × M3 × 12.
2. hand_adapter onto the wrist motor's boss — 4 × M2 × 5 countersunk, while you can still reach them.
3. Push the hand onto the adapter until the snap clicks. No screws in the hand.

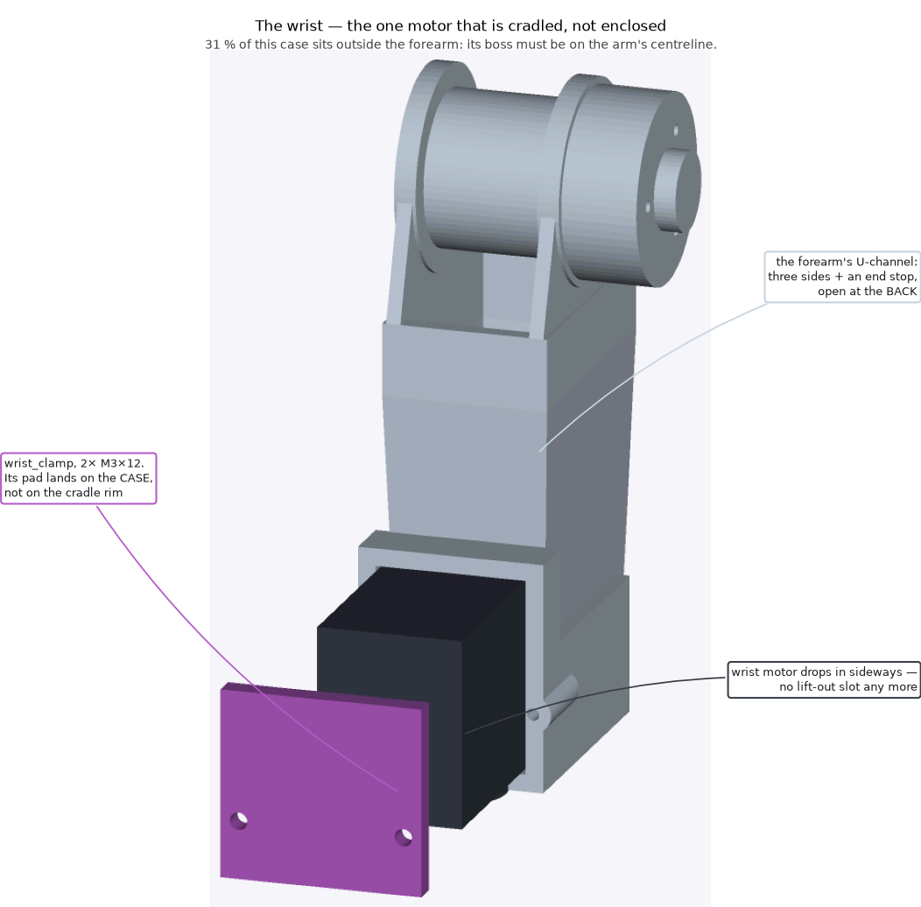
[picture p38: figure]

The wrist motor drops into the forearm's cradle from the back and the clamp bar holds it.
Step 5 — Elbow
1. Loop the 140 mm belt over a 40-tooth pulley and over the elbow motor's 20-tooth pulley, motor still loose.
2. Bolt that 40-tooth pulley to the forearm's elbow hub — 3 × M2 × 16, on the outboard face — with the belt still around it.
3. Slide the elbow motor (16 / 20) into the pocket in the upper arm from the back — it lies flat, long side front to back. Fix it with 2 × M2 × 6 and washers through the front face.

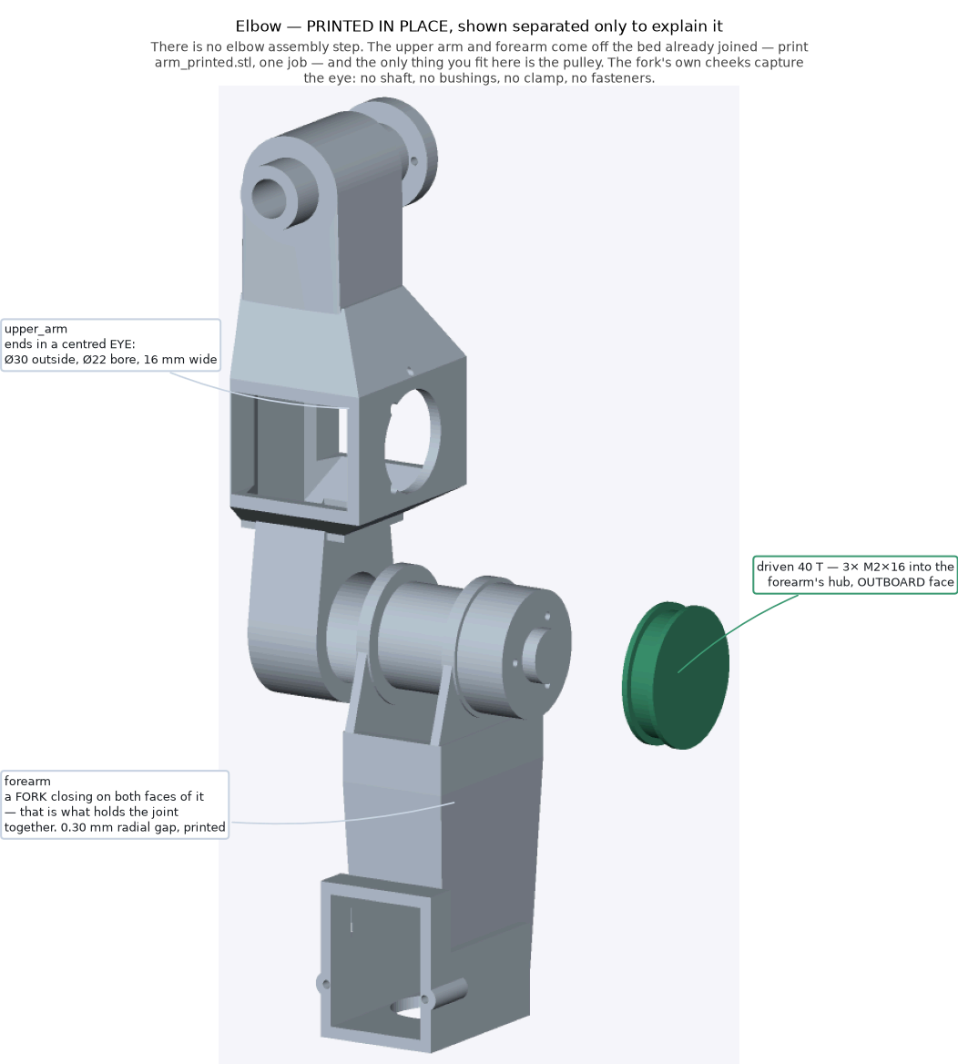
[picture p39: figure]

The elbow: the belt goes on first, then the motor slides in from the back.
Step 6 — Shoulder roll
1. Loop a 122 mm belt over the roll motor's 20-tooth pulley, and over a 40-tooth pulley.
2. Bolt that 40-tooth pulley to the collar on the far side of the fork's outer cheek — 3 × M2 × 16. It drops onto a round spigot and should go on with a firm push and no rock.
3. Drop the roll motor (15 / 19) onto the fork's cradle from the outside, and fix it with 2 × M2 × 20 through the back face.

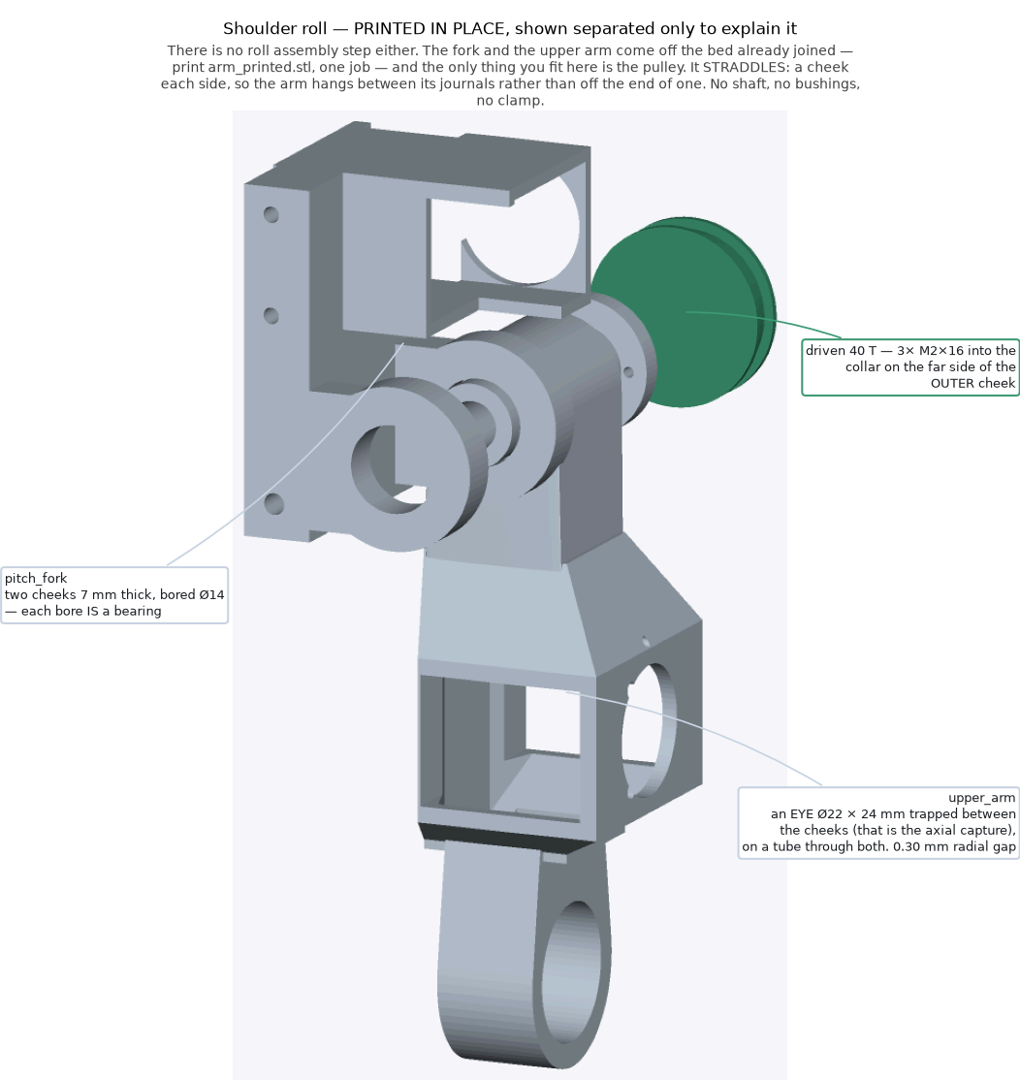
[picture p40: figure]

Shoulder roll: the belt over both pulleys, then the motor down onto the fork's cradle.
Step 7 — Shoulder pitch
1. Loop a 122 mm belt over the fork's pitch pulley (fitted in step 2) and the pitch motor's 20-tooth pulley.
2. Slide shaft_pitch_44mm in from the body side: through both housing bushings, through the pulley, and into the fork's pitch hub. Fit whichever collar (2, 3 or 4 mm) stops the shaft sliding end to end.
3. Pin the shaft to the fork (mentor): drill 2.5 mm straight up from the underside of the fork's back plate, through the hub and the shaft together, and drive in an M3 self-tapping screw or a 2.5 mm pin. This is the only thing that stops the shaft walking out. Don't skip it.
4. Lower the pitch motor (14 / 18) into the housing's bay from above. Start its two M2 × 6 screws in the lower pair of slots, finger tight.
5. Tension the belt: put a small flat screwdriver through the little window in the front of the bay and lever the motor backwards against the belt, then tighten the two screws while you hold it there. A fraction of a millimetre is normal.

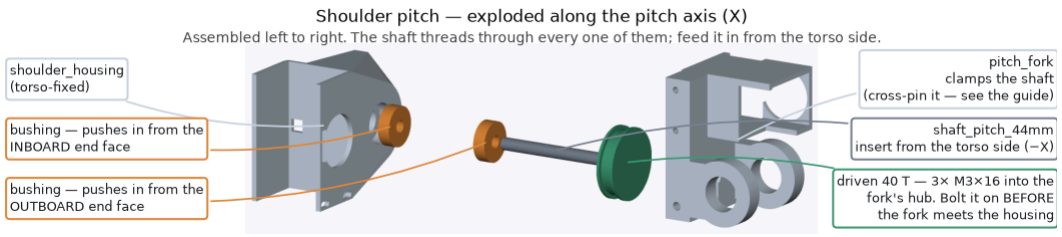
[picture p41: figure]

Shoulder pitch: the shaft goes in from the body side; the motor drops into the housing from above. (The picture's label says M3 × 16 for the big pulley — that's out of date: it's M2 × 16, as in step 2.)

Step 8 — Belt covers

Last, once both belts are on and both motors are fixed. Each cover pins into the bore of both its pulleys and is held by one M2 × 16 countersunk screw.

1. Line the big pin up with the 40-tooth pulley's bore and the small pin with the 20-tooth pulley's socket, and drop it on. Both pins are loose, and that's right — each pulley keeps turning under its pin. Never force a cover on.
2. Drive the screw through the cover into the fork (roll) or the upper arm (elbow). Nip it up, don't crank it.
3. Spin each pulley with a fingertip before and after the screw goes in. Stiff before means a pin is too tight in its bore; free before and stiff after means the screw is too tight.

The pitch belt has no cover — it's walled in by the body.

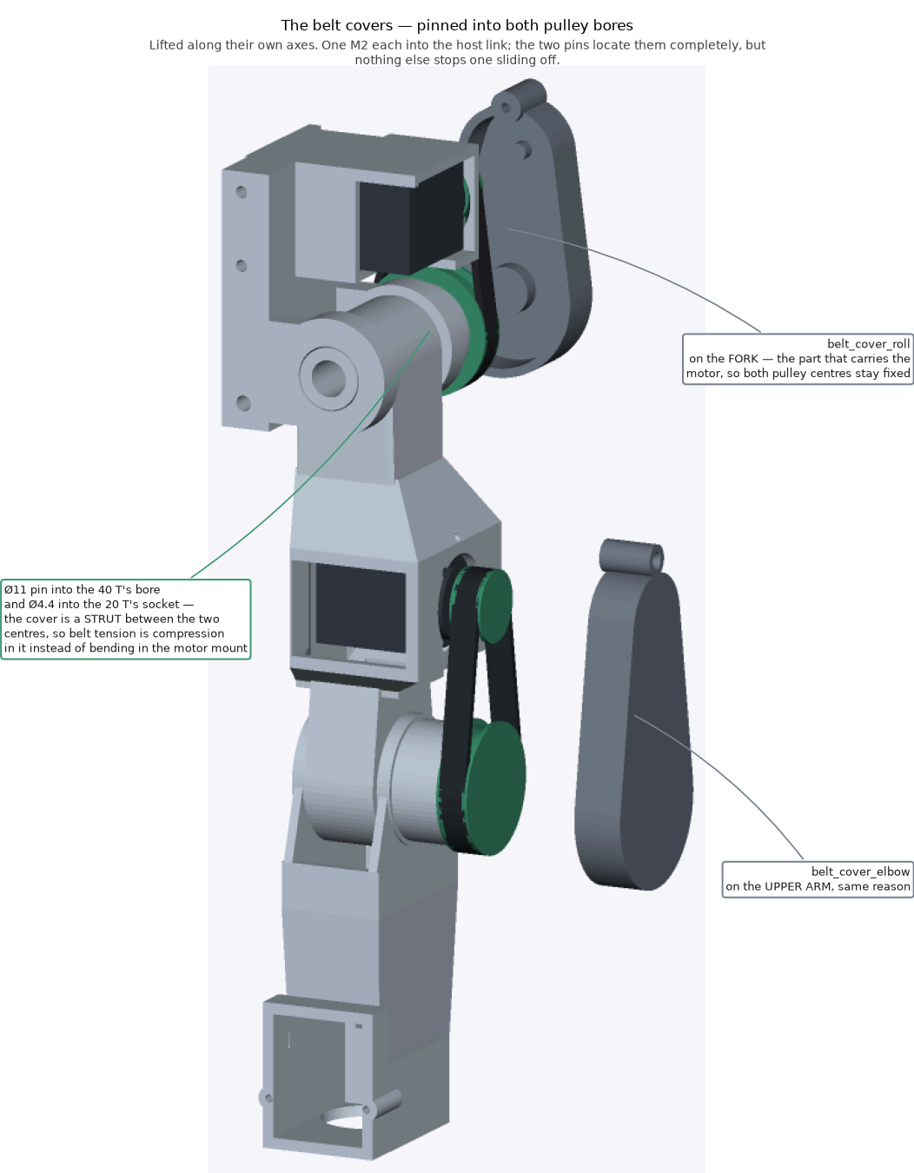
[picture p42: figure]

The two belt covers, lifted off. Each one is also a strut that holds its two pulleys apart.
Belt tension, all three: a belt should give a couple of millimetres under a firm thumb in the middle and make a dull thud, not a note. Too tight wears out the motor's bearings.

✅ Checkpoint 3.5

☐ Both arms built, every motor in the right place for its label
☐ With the motors unpowered, every joint turns by hand through its range with nothing rubbing and no belt jumping teeth
☐ Each pulley turns under its belt cover
☐ The pitch shaft is pinned on both arms
☐ A scan finds 14–17 and 18–21

## 6. The arms onto the body

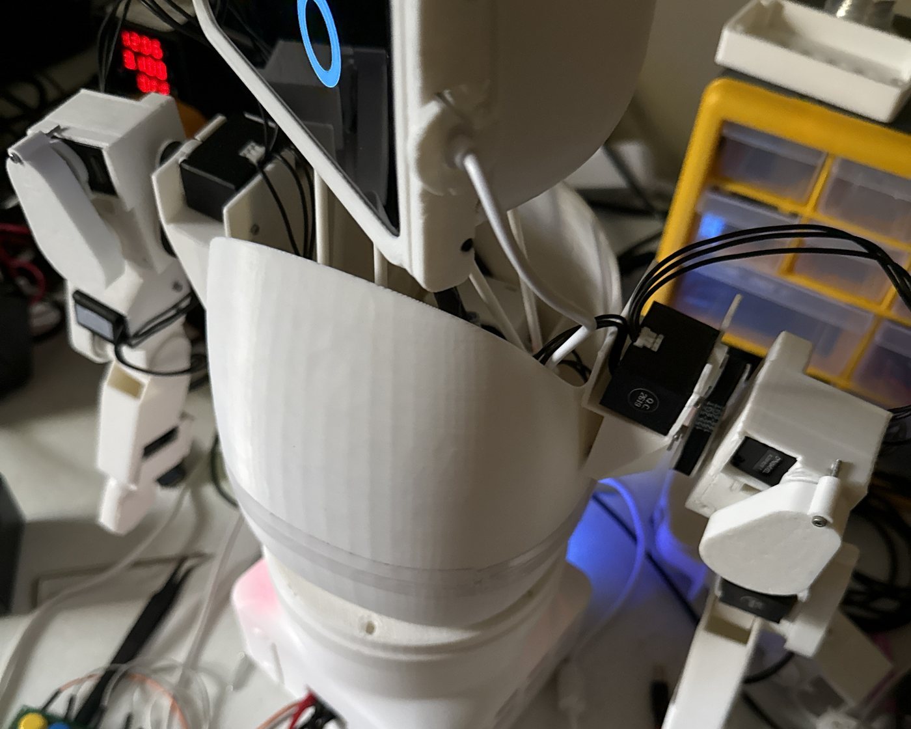
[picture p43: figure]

Ollie's shoulders: each shoulder housing is screwed to the top of the body, where the shell narrows, and the arm hangs outside it. The motor cables go in over the top.
The shoulders screw straight through the body shell. There's no printed bracket for this — Ollie's were fitted by hand — so R1 works out the exact position first, with the mentor, and writes it down (distance below the top rim, distance from the front seam) so all six robots match. After that, a paper template taken off R1's body lets the other teams mark and drill their shell before anything is inside it.
1. Hold each arm where Ollie's is: its shoulder housing at the top of the body where the shell narrows, one on each side and level with each other, the arm hanging outside the shell.
2. Mark the housing flange's four holes onto the shell, then drill 3.2 mm (a small pilot hole first). Clean off the swarf, and keep it out of the head motors below.
3. Bolt each housing on with 4 × M3 screws and nuts (R1 confirms the length — about 12 mm).

4. Run both arms' motor cables in over the top of the body to the motor chain, as in the photo. Leave enough slack for the arm's full swing, and strain-relieve every connector.

✅ Checkpoint 3.6

☐ Both shoulders solid on the body, at the same height, with no rocking
☐ With the motors unpowered, the head moves by hand through its whole range without touching either shoulder or an arm cable
☐ Each arm swings through its range without hitting the body
☐ A scan still finds 1–9 and 14–21

## 7. The base and yaw joint

The robot stands on a printed plinth with a 6816 bearing on top. The body-turn motor (ID 3) hangs under a bridge in the top of the base and turns the rotor directly. Cables go straight up through the middle of the bearing.

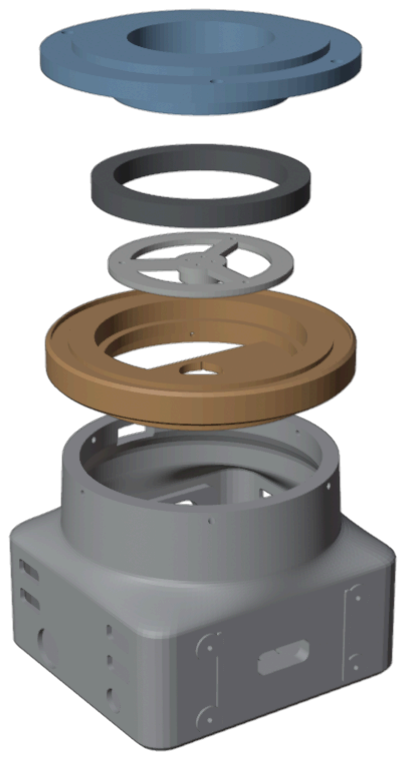
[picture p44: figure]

The base, pulled apart, bottom to top: the plinth (grey), the stator cap (orange) with the yaw motor hanging under its bridge, the clamp and drive hub (white), the 6816 bearing (dark), and the rotor (blue) that the body sits on.
Do it in this order — it's the order in which every screw can still be reached:
1. Electronics into the plinth (step 8 says what goes where). The top opening is ⌀117 mm.

2. Yaw motor up under the cap's bridge, boss through the hole: 4 × M2 × 8 down through the bridge. Send it to the middle of its range first ( calibrate show must say (loaded) , then calibrate home twice), and don't turn it by hand after that. When you choose which holes line up in steps 3 and 6, pick the combination that leaves the body facing forward (within about 15°). The body turns 90° each way; starting from the middle keeps that clear of the motor's seam.
3. Clamp / hub down onto the motor's boss: 4 × M2 × 10.
4. Bearing into the cap's pocket.
5. Rotor spigot down through the bearing onto the clamp.
6. 3 × M3 × 8 countersunk up from below at 30°, 150° and 270°, in the hole combination you chose in step 2.
7. Four brass spacers into the rotor's pockets, then lower the body onto the rotor's ring. The body's own four clamshell screws (the longer ones) go up from under the rotor, through the spacers, into the body — one set of screws holds the body shut and holds it on.
8. Cap into the plinth: 6 × M3 × 14, sideways through the drum wall.
9. Record the body's centre: with the body facing straight forward, run motor_status.py --ids 3 and put the reading into the file as the center of body_yaw , with min 1536 below it and max 1536 above it (both must stay inside 0–4095). Save, show must say (loaded) , and back the file up to the USB stick.

To service the base later, undo the six screws in step 8 and the whole robot lifts off with the joint intact.

Cable loop. The body turns up to 90° each way, carrying the head, the arms and every cable with it. Leave enough slack in the cables passing up through the middle that a full turn each way pulls on nothing, and tie them so they can't rub on the bearing or a printed edge.

✅ Checkpoint 3.7

☐ With the yaw motor unpowered, the body turns smoothly by hand 90° each way with all cables connected — no rubbing, no tugging
☐ The body doesn't rock on the rotor
☐ The body's centre is in the calibration file

## 8. Power and cables

wall ─ 12 V brick ─┬─► 12→5 V converter ──► U2D2 Power Hub ──► all 17 motors
└─► 12→5 V USB charger ──► USB-C cable up through the body ──► phone

wall ─ official Pi 27 W supply ──► Raspberry Pi 5 ──USB──► U2D2 ──► Power Hub (data)

The 12 V side — the brick, the fuse, the switch and the converters — is mentor work and is wired and measured as Appendix B describes. The Pi keeps its own official supply: a general-purpose 5 V supply measured too low on Ollie and made the Pi crash.

1. Mentor: measure the motor supply before any motor is connected — probes on the Power Hub's input, power on: about 5.0 V. If it says 12, stop.

2. Power Hub into its tray (4 × M3 from above), tray into the rails in the plinth. The converters go in the plinth too.
3. The Pi goes in its case: Active Cooler on, Pi on the standoffs (4 × M2.5 × 8), cover on. The case stands on the table beside the plinth and bolts to its right side (4 × M3 × 16) — the screws only locate it, the table carries it.
4. Short USB cable from the Pi to the U2D2, inside the base.
5. Motor chain from the Power Hub up through the yaw joint to the body, then on to the head and both arms.
6. The phone's charging cable from the USB charger up through the yaw joint and the body to the head (the route you planned in step 4).
7. Tie down every cable in the base. Nothing loose, nothing crossing the yaw joint or a printed edge where it can rub. On Ollie, the motors once lost power for eleven minutes and came back only when the cables in the base were moved — most likely a short from a loose wire.

Leave the monitor and keyboard on the Pi: you need them for Stage 4.

✅ Checkpoint 3.8

☐ 5 V measured at the Power Hub before the motors were connected
☐ With the Pi running and the motors powered, a scan from the Pi finds all 17 motors ☐ No loose cable anywhere in the base; the body still turns freely 90° each way

S TAG E 4 · S O F TWARE

# Stage 4 — Software installation

The robot software went onto the Pi in Stage 2. This stage turns it into your robot: its name and settings, a first start, the head's limits and the arms' zeros, starting by itself, and the phone face. Everything is done on the Pi, with its monitor and keyboard.

Step | What | Who
1 | The robot's name and settings | Software lead
2 | First start | Software lead + mentor
3 | The head's limits, by hand-posing | Mentor + two students
4 | The arms: zeros, directions, test | Mechanical lead + mentor

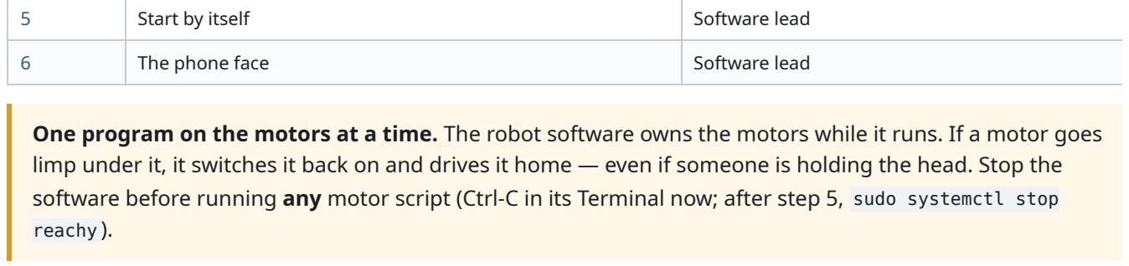
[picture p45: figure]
Start by itself; Software lead; The phone face; reachy ).

One program on the motors at a time. The robot software owns the motors while it runs. If a motor goes limp under it, it switches it back on and drives it home — even if someone is holding the head. Stop the software before running any motor script (Ctrl-C in its Terminal now; after step 5, sudo systemctl stop

## 1. Name and settings

Give the robot a name — the team's choice, short, easy to say, and not like any other robot's (not "Ollie", and not two names that rhyme). The name is what the robot answers to, and six robots with similar names means one call wakes six.

Open the settings file:

cd ~/reachy
nano .env
1. Find the line WAKE_WORD=Ollie (Ctrl-W, type WAKE_WORD , Enter) and change Ollie to your robot's name:
WAKE_WORD=Nova .
2. Go to the very bottom of the file (Ctrl-End, or hold the down arrow) and add this line, which makes the voice come out of the phone in the head:

SPEAK=face

3. Ctrl-O, Enter to save, Ctrl-X to exit. Leave everything else as it is.

## 2. First start

1. Check the calibration file one more time: .venv/bin/python -m scripts.calibrate show must say (loaded)
and show your numbers.

### 2. Start the robot software by hand:

./run.sh

The head rises to level and holds. Keep a hand near the Power Hub's switch the first time.
3. Open the web browser on the Pi and go to http://localhost:8080 — the robot's console. It shows your robot and has buttons for its gestures, head poses and voice.
4. Go to http://localhost:8080/health . It should show "backend": "dynamixel" , and inside "backend_health" : "motors" listing 1–9, and "calibrated": true .
5. Ctrl-C in the Terminal stops the robot.

## 3. The head's limits, by hand-posing

Mentor, with one student supporting the head and one at the keyboard.

The robot knows where "level" is. Now it learns how far the head can go in each direction. The capture tool needs the motors to itself, so the robot software must be stopped (Ctrl-C).

cd ~/reachy
.venv/bin/python -m scripts.calibrate show
.venv/bin/python -m scripts.calibrate capture pitch down 25

The head goes to level, then limp. Pose it to that limit, press Enter, and it saves the motor positions and goes back to level. Do all eight:

Command | Pose it to
capture pitch down 25 / capture pitch up -25 | chin down / chin up, as far as it goes comfortably
capture roll right 20 / capture roll left -20 | tilt to the robot's right / left
capture yaw right 25 / capture yaw left -25 | turn to the robot's right / left
capture z up 12 / capture z down -12 | lift the whole head straight up / lower it straight down

⚠️ Support the head at the chin and the crown, and rotate it — don't push it. A hand on the chin pushes the whole head down while it tips, and that slide gets recorded as part of the nod: on Ollie the first nod came out as a forward head-thrust. The next command strips the slide back out, using the two z captures as the reference. Keep the raw file first:

cp data/motor_calibration.json data/motor_calibration.raw.json python3 scripts/clean_calibration.py
python3 scripts/clean_calibration.py --write data/cleaned.json mv data/cleaned.json data/motor_calibration.json
.venv/bin/python -m scripts.calibrate show

The first clean_calibration line only reports; the second writes the cleaned file. show must still say (loaded) .
Copy both motor_calibration.json and motor_calibration.raw.json onto the USB stick — the raw one is how
the cleaning can be redone.

Now check the directions: start the robot ( ./run.sh ) and on the console press Look R (under Head pose). The head must turn to the robot's own right. Then drag the Head roll slider (on the Manual controls card) to the right: the head must tilt to its own right. If one is mirrored, the two captures for that axis were swapped — capture them again the other way round.

## 4. The arms

The arms have no "level" to record. Each joint's zero is captured with the arm hanging straight down, after it's built, and that's the reference every angle is measured from.

The arm goes limp when you're not driving it, and a limp arm falls. Keep hands and faces clear of it, and keep the mouse near the PANIC button. Watch the first move of every joint with a hand ready on PANIC: these arms have never been zeroed on this robot before, and a joint that has its sums wrong can try to go a long way.

1. Start the robot ( ./run.sh ) and open http://localhost:8080/limbs on the Pi.
2. Pick the right side. Press 🔍 Find motors — it finds the arm's four motors and moves nothing. (The title at the top of the page always says "right arm"; trust the side buttons.)
3. Let the arm hang at rest: straight down, the forearm in line with the upper arm, the palm facing the body. Hold it still and press ⦿ Capture zero.
4. Tick Drive the real arm. The arm switches on and holds exactly where it is.
5. Check each joint's direction. Move each slider a little way and watch the real arm: shoulder pitch should swing the arm forward, shoulder roll should lift it out to the side, the elbow should bend the forearm forward, and the wrist should turn the hand. If a joint goes the wrong way, press its ⇄ button — that's safe while the arm is live.

If a slider moves the wrong joint — the pitch slider moves the roll joint, say — two motors are in each other's places, and ⇄ can't fix that. Untick Drive the real arm, pick the right motor from that joint's id list (picking one another joint holds swaps the two), press 🔍 Find motors, and check the directions again. 6. Press 🎯 Test live robot. It moves each joint a little, one at a time, and checks that it really moved. If it stops and lets the arm go limp, it found a joint that didn't move — a slipped belt or a stuck joint. Fix that before going on. 7. Untick Drive the real arm, pick the left side, and do steps 2–6 again. 8. Make the arms come up with the robot: stop the robot (Ctrl-C), open .env in nano , find ARM_START=off and change it to:

ARM_START=both

An arm goes limp after about 15 seconds with no command and switches back on by itself at the next one. That's normal, and it's what stops a motor holding a pose until it overheats.

## 5. Start by itself

When the head and both arms are calibrated, make the robot start whenever the Pi does:

cd ~/reachy
bash scripts/provision_pi.sh --service
sudo systemctl restart reachy

Restart the Pi ( sudo reboot ). About 15 seconds after the desktop appears, the head goes level on its own and
http://localhost:8080 shows the console.

From now on the robot software owns the motors whenever the Pi is on. Before any motor script:

sudo systemctl stop reachy
pgrep -af 'app\.main|app\.serve'

The second line must print nothing (if it prints anything, the software is still running). Run your script, then
sudo systemctl start reachy afterwards.

## 6. The phone face

The phone is set up before it goes into the head — once it's inside, its settings are hard to reach.

1. Check the battery: the back glass must sit flat. A swollen phone never goes in a head.
2. Turn on Stay awake: Settings → About phone → Software information, tap Build number seven times to unlock Developer options, then Settings → Developer options → Stay awake.
3. Turn auto-brightness off and set the brightness by hand. Set the screen timeout to the maximum.
4. Put the phone on the same wifi as the Pi.
5. On the Pi, open http://localhost:8080/pair?audio=1 . It shows a QR code. Scan it with the phone's camera, open the page, and in Chrome's menu (⋮) choose Add to Home screen. (The ?audio=1 matters: plain /pair makes the phone the eyes only, with no voice.)
6. Open the face from the new home-screen icon. Tap it once — phones stay silent until they're tapped. The eyes are amber until that tap, then they turn to normal.
7. Touch the face and press 🔊 Test audio. It should speak.
8. Into the head: slide the phone into the face plate, screen forward, charging port at the service-cap end. The last few millimetres take a firm push — that's the plate's pads pressing the phone onto the front lip, and it's what stops the rattle. Plug in the charging cable, lead it out past the cap the way Ollie's is, and fit the service cap: tongue in, 2 × M2 × 10 self-tapping. Don't pinch the cable.

Whenever the phone's page reloads — after the robot restarts, say — the eyes go amber again and it needs one tap before it can make a sound.

Back up: copy data/motor_calibration.json , data/motor_calibration.raw.json and .env onto the USB stick.
( .env starts with a dot, so the file manager hides it — press Ctrl-H to show hidden files.)

✅ Checkpoint 4

☐ WAKE_WORD in .env is set to the robot's own name
☐ After a restart it comes up by itself: the head goes level and holds, /health shows "backend":
"dynamixel" and, inside "backend_health" , motors 1–9 and "calibrated": true
☐ Look R turns the head to the robot's own right, and Head roll tilts it the right way
☐ Both arms passed 🎯 Test live robot, and /health shows both arms "zeroed": true
☐ The phone shows the eyes, speaks, and is charging inside the head
☐ The calibration files and .env are backed up on the USB stick

S TAG E 5 · T E S T I N G

# Stage 5 — Testing

Three tests, in this order: the acceptance test (is the robot sound?), the Code Lab (can you program it with blocks and JavaScript?) and VR control (can a headset drive it?). A robot is done when every box in this chapter

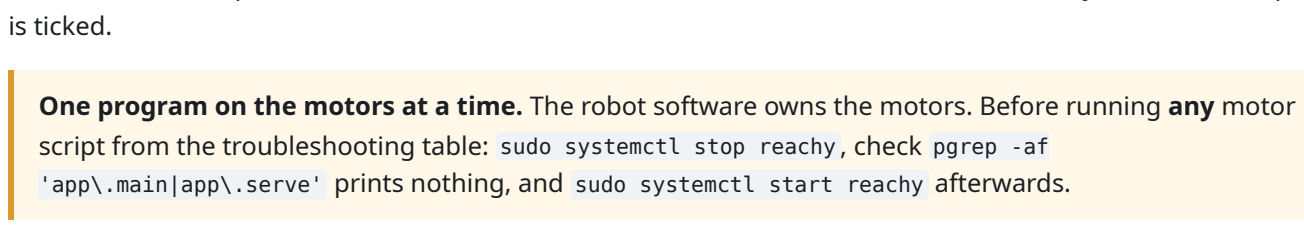
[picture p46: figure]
is ticked.

One program on the motors at a time. The robot software owns the motors. Before running any motor script from the troubleshooting table: sudo systemctl stop reachy , check pgrep -af
'app\.main|app\.serve' prints nothing, and sudo systemctl start reachy afterwards.

Finding the robot's address. The Code Lab and VR are opened from other devices, which need the Pi's address on the wifi. In a Terminal on the Pi, hostname -I prints it — the first number, like 192.168.1.57 . The robot's
pages are at http://<that address>:8080 .

## 1. Acceptance test

The whole team, with the checklist.

☐ Start-up: unplug everything, plug it back in. The robot comes back on its own in under a minute; the head goes level; the face shows eyes (tap once for sound)
☐ Gestures from the console: 👋 Greet · 😌 Nod · 📡 Wiggle · 👀 Look · 🎉 Celebrate · 🤔 Think — smooth, no clicking, no binding, no rod pops
☐ Antennae move, and "left" is the robot's own left
☐ Body turn — 90° each way and back, with the arms and every cable coming along cleanly
☐ Arms: after a restart, on /limbs , tick Drive the real arm and 🎯 Test live robot passes on both sides — without anyone capturing a zero again
☐ Voice: it says a line out of the phone; the mute switch on the console silences it
☐ 30-minute run, used the way it will be at a demo: every few minutes play a few gestures, turn the body, and run a Code Lab show with the arms in it (section 2). Afterwards (software stopped) motor_status.py shows no hardware errors, no motor is too hot to hold a finger on, and the mentor checks the 5 V converter is warm, not hot
☐ Everything labelled; the team log up to date (ID map, calibration date, who did what)

## 2. The Code Lab — Blockly and JavaScript

The Code Lab is where students program the robot. You build a show out of blocks (Blockly) or write it in JavaScript, watch a cartoon of the robot act it out, and then run it on the real robot. The two are connected: Show me the code turns your blocks into the JavaScript that does the same thing, so you can move from blocks to typing without starting over.

The block palette isn't stored in the page — it's built from the robot's own list of gestures, moods, head poses and arm poses. So if the blocks appear, the page is talking to your robot. (The page calls every robot "Ollie": it's the same software.)

Open http://<robot's address>:8080/lab — on the Pi itself it's http://localhost:8080/lab , but try it from a
laptop, tablet or phone on the same wifi too, because that's where students will use it.
1. Blocks. The 🧩 Blocks tab shows a palette of robot blocks. Drag in a say block and type "Hello", then a do a block and pick celebrate from its list. Press ▶ Run. What Ollie will do shows the robot's script, and the preview plays it. Open the lists on the do a and look blocks: those are your robot's own gestures and head poses.
2. Blocks → JavaScript. Press Show me the code. The ⌨️ JavaScript tab opens with your blocks written as
code, something like ollie.say('Hello'); and ollie.gesture('celebrate'); . Change the words in the
code and press ▶ Run — the preview says the new words. That's the connection working in both directions: blocks became code, and the code runs.
3. A loop. Press ↺ Example. It loads a program with a for loop that waves the antennae three times — the kind of thing blocks can't say as neatly. Press ▶ Run and watch the preview.
4. On the real robot. Press 🤖 Run on Ollie. The real robot performs the program: the voice from the phone, the antennae, the arm wave. ⏹ Stop stops it. ⤼ Step runs one action at a time — the way to find which line does what.
5. Send it in. Type a name for the show and your name, and press Submit. It goes to the teacher's review list on the console, where a teacher can approve it.

✅ Checkpoint 5.2

☐ The block palette appears (the page reached the robot)
☐ Show me the code turns blocks into JavaScript, and an edited program runs in the preview
☐ 🤖 Run on Ollie makes the real robot perform it, and ⏹ Stop stops it
☐ It works from a second device on the same wifi, not just the Pi

If it goes wrong: no blocks at all means the page couldn't load the block library or reach the robot — check the address, and tell the mentor (the software may be missing its Blockly file). If Run on Ollie says an arm isn't ready, that side isn't live and zeroed — go back to Stage 4, step 4.

## 3. VR control

With a Meta Quest headset you can stand next to a life-size virtual copy of your robot. Hold a grip button and the real robot's head follows your head. Hold the trigger and talk, and your voice comes out of the robot. The virtual robot moves along with the real one.

⚠️ Two people. The person in the headset can't see the real robot. The second person watches the robot the whole time, with a hand near the Power Hub's switch, and says out loud what it's doing. VR never moves the arms — on purpose, for exactly this reason.

Once per robot: a certificate (mentor)

A headset only allows VR on a secure (https) page, so the robot needs a certificate:

cd ~/reachy
bash scripts/make_cert.sh
.venv/bin/pip install numpy
sudo systemctl restart reachy

( numpy is what lets the robot change your voice into its character voices. Without it, VR still works, and you hear your own voice.) Two things change, and both are expected:

The robot's pages move to https://<address>:8080 . Browsers warn that the certificate isn't trusted, because it's home-made. Press Advanced → Proceed (on the Pi, the console is now
https://localhost:8080 ).
Plain http moves to port 8081. The phone face uses plain http, so its home-screen icon stops working. On the phone, open http://<address>:8081/eyes?audio=1 , tap once, choose Add to Home screen again, and delete the old icon.

The test

1. Put the Quest on the same wifi as the robot. In the Quest's browser, open https://<address>:8080/vr and press Advanced → Proceed.
2. The flat page shows your robot in 3D, moving when the real one moves.
3. Press Enter VR. Allow the microphone when asked — it can only ask here, before you go in.
4. The robot stands in front of you, life-size.
5. Head. Hold a grip button and turn your head to your right — the real robot turns to its right. Nod — it nods. Tilt — it tilts. Let go — it stops where it is. The watcher says whether each direction matched. If one is backwards, write down which, and tell the mentor (it's one setting to flip).
6. Voice. Hold the trigger and talk. When you let go, your voice — shifted towards a robot character — comes out of the phone in the robot's head. The waveform under the Voice button moves while you talk; if it stays flat, the microphone isn't reaching the page. Pressing Voice changes the character.
7. Control panel. On the panel beside you, the Motion tab has the gestures: press one and the real robot does it.
8. Exit VR — the button above your eyeline, apart from everything else.

✅ Checkpoint 5.3

☐ The virtual robot appears and follows the real one
☐ Holding a grip drives the real head, in the right direction on all three axes, and letting go stops it ☐ Your voice comes out of the robot, and the waveform moves when you talk
☐ A gesture from the panel plays on the real robot
☐ The phone face was re-added on port 8081 and still speaks

## 4. When something goes wrong

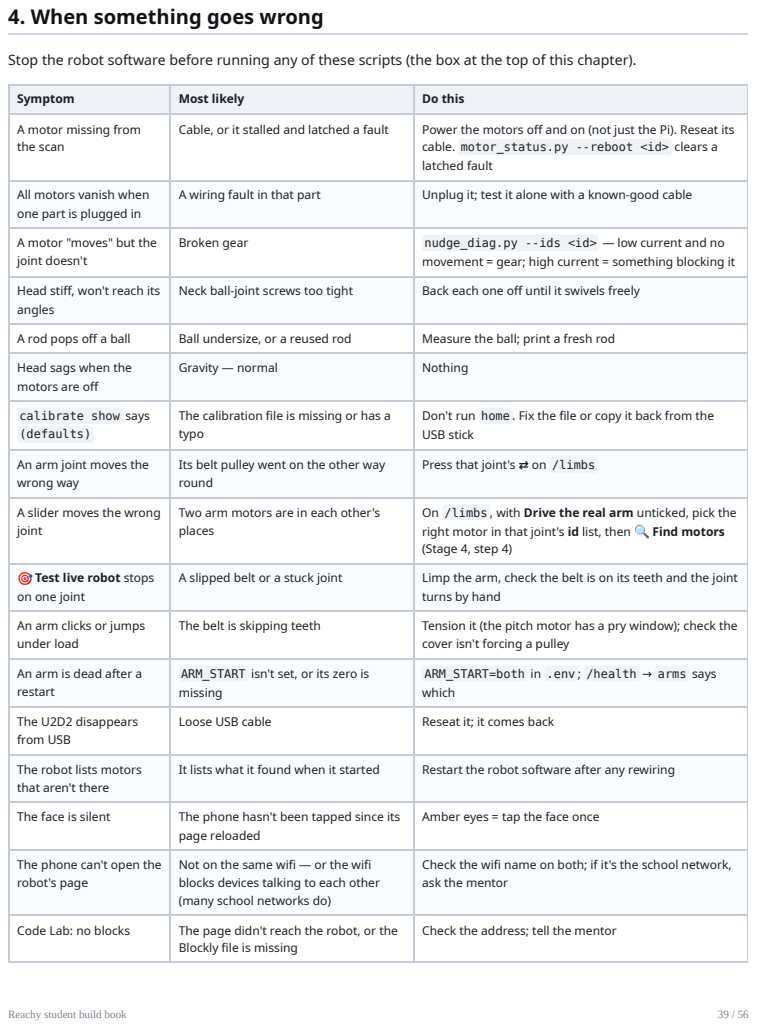
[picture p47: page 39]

Stop the robot software before running any of these scripts (the box at the top of this chapter).

Symptom | Most likely | Do this
A motor missing from the scan | Cable, or it stalled and latched a fault | Power the motors off and on (not just the Pi). Reseat its cable. motor_status.py --reboot <id> clears a latched fault

All motors vanish when one part is plugged in | A wiring fault in that part | Unplug it; test it alone with a known-good cable

A motor "moves" but the joint doesn't | Broken gear | nudge_diag.py --ids <id> — low current and no movement = gear; high current = something blocking it

Head stiff, won't reach its angles | Neck ball-joint screws too tight | Back each one off until it swivels freely

A rod pops off a ball | Ball undersize, or a reused rod | Measure the ball; print a fresh rod
Head sags when the motors are off | Gravity — normal | Nothing

calibrate show says (defaults) | The calibration file is missing or has a typo | Don't run home . Fix the file or copy it back from the USB stick

An arm joint moves the wrong way | Its belt pulley went on the other way round | Press that joint's ⇄ on /limbs

A slider moves the wrong joint | Two arm motors are in each other's places | On /limbs , with Drive the real arm unticked, pick the right motor in that joint's id list, then 🔍 Find motors (Stage 4, step 4)

🎯 Test live robot stops on one joint | A slipped belt or a stuck joint | Limp the arm, check the belt is on its teeth and the joint turns by hand

An arm clicks or jumps under load | The belt is skipping teeth | Tension it (the pitch motor has a pry window); check the cover isn't forcing a pulley

An arm is dead after a restart | ARM_START isn't set, or its zero is missing | ARM_START=both in .env ; /health → arms says which

The U2D2 disappears from USB | Loose USB cable | Reseat it; it comes back

The robot lists motors that aren't there | It lists what it found when it started | Restart the robot software after any rewiring

The face is silent | The phone hasn't been tapped since its page reloaded | Amber eyes = tap the face once

The phone can't open the robot's page | Not on the same wifi — or the wifi blocks devices talking to each other (many school networks do) | Check the wifi name on both; if it's the school network, ask the mentor

Code Lab: no blocks | The page didn't reach the robot, or the Blockly file is missing | Check the address; tell the mentor

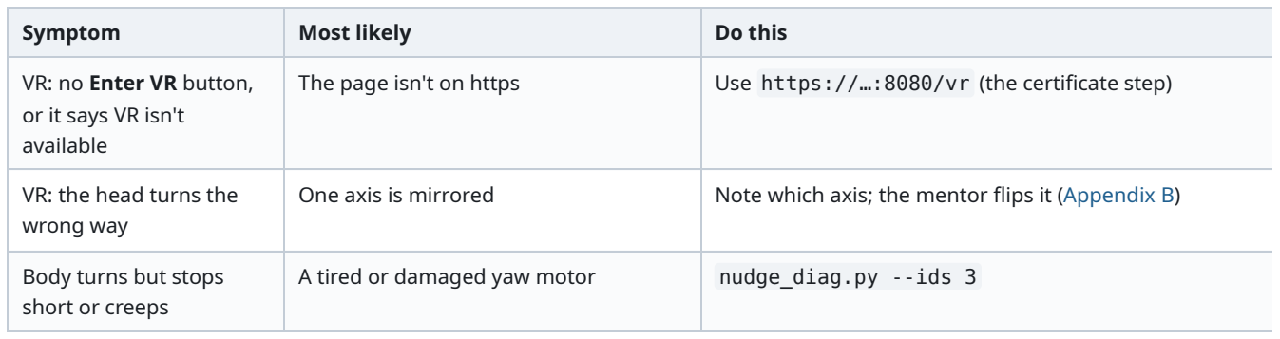
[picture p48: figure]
Symptom; Most likely; Do this

VR: no Enter VR button, or it says VR isn't available | The page isn't on https | Use https://…:8080/vr (the certificate step)
VR: the head turns the wrong way | One axis is mirrored | Note which axis; the mentor flips it (Appendix B)
Body turns but stops short or creeps | A tired or damaged yaw motor | nudge_diag.py --ids 3

S TAG E 6 · M AKE I T YO U RS

# Stage 6 — Make it yours (optional)

Your robot works. Everything in this chapter is optional, and none of it should be started until your robot has passed Stage 5 — a customisation is much easier to trust on a robot you already know works.

Customisation | Effort | Who
Name, voice and eyes | Minutes, on the console | Anyone
Your own head, designed in Blender | Days — design, check, print | Designer + team
A different phone for the face | A reprinted face plate | Mentor + team

## Name, voice and eyes

Name. WAKE_WORD in .env (Stage 4). Change it with nano .env , then sudo systemctl restart reachy .
Voice. The console's ️ Speech & voice card picks the robot's voice from a list of characters, and has sliders for how fast it talks. The robot remembers your choice after a restart.
Eyes. Touch the phone's face and a bar rises from the bottom: ◀ / ▶ step through 36 eye styles, named as you go. Pick one before the head is closed up.
A more natural voice (mentor). Out of the box the Pi speaks with espeak, which sounds properly robotic. For smoother voices, on the Pi:

cd ~/reachy
bash scripts/fetch_voices.sh
bash scripts/provision_pi.sh --voices sudo systemctl restart reachy

It needs internet and about 500 MB of space.

## Your own head

The next chapter, Designing your robot's head in Blender, is the big one. You start from the standard head and add ears, horns, a crest, a visor or your robot's name, and a script checks your design against every rule the robot needs before it exports the file you print. Blender runs on a Windows, Mac or Linux computer — use a school computer for it, not the robot's Pi.

## A different phone

The face plate is made for a Samsung Galaxy S10 (model SM-G973) to a fraction of a millimetre: 149.9 × 70.4 × 7.8 mm, 157 g. The plain S10 — not the S10e, S10+ or S10 5G. A different phone means a new face plate, made by the mentor from the phone's measurements.

A phone is a good candidate if:

it's Android with Chrome. An iPhone can show the face, but it can't reopen the page by itself after a power cut, and a sealed head needs that;
it's close to the S10's size. The S10 is already as wide as the head (150 mm), so a longer phone sticks out at the sides;
it's no heavier than 157 g. Six small motors hold the head up, and the phone is most of its weight;
it has an OLED screen if possible, so the black around the eyes is truly black;
its battery is not swollen — the back sits flat.

Making the new plate:

1. Measure the phone with calipers, to 0.1 mm: length, height, thickness. Weigh it. Note where its rear camera bump is.
2. Mentor: put the three measurements into PHONE_W , PHONE_H and PHONE_T at the top of hardware/s10-face/generate_s10_face.py in the robot's main repository, regenerate the plate and cap, and run the fit check ( verify_s10_face.py ). The S10's camera relief ( CAM ) and screen window ( WIN_W , WIN_H ) are there too. The file's README says how.
3. Print a test plate first, exactly like the face-plate test print in Stage 1: the phone slides in with a firm push at the end, the cap screws shut, and nothing rattles.
4. Set the eyes' size on the new phone: touch the face, press ⚙, hold a ruler against the blue bar and adjust it until it is exactly 50 mm. The face then draws its eyes at the right size on that screen.
5. Set the new phone up as in Stage 4, step 6 — Stay awake, brightness, pairing, one tap.

⚠️ A heavier phone changes how the head moves. After fitting one, re-run the acceptance test in Stage 5, and if the head sags or struggles to reach its limits, go back to the S10.

S TAG E 6 · YO U R OWN H EA D

# Designing your robot's head in Blender

Every robot gets the same neck, body and base — they hold motors, a phone and a computer, and their shapes are measured to a fraction of a millimetre. The head is yours. You start from the standard head and add to it: ears, horns, a crest, a visor, a badge, your robot's name engraved on its side. A script checks your design against every rule below and exports the file you print.

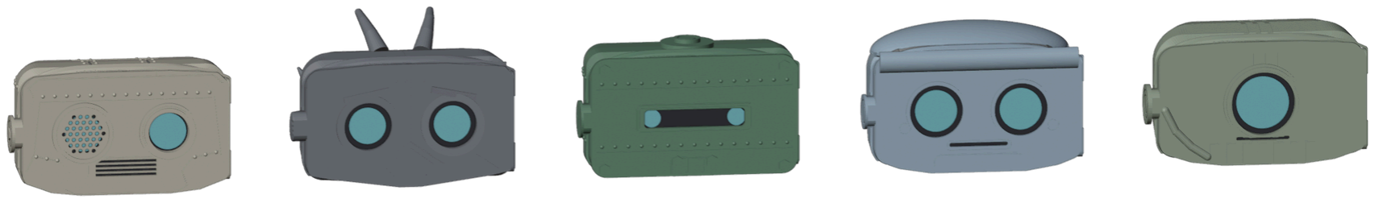
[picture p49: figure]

The character heads designed for the original robot — tinhead, vex, boiler, pip and iris. Every one fits the same neck and the same phone. Yours will too.

## 1. Set up

1. Install Blender 4.5 LTS from blender.org (https://www.blender.org/download/) (any version from 4.2 up works). It's free and runs on Windows, Mac and Linux.
2. Optional but useful: the 3D Print Toolbox add-on. Edit ▸ Preferences ▸ Get Extensions, search "3D Print Toolbox", Install. It checks wall thickness and overhangs.
3. Get the starter file, reachy_head_starter.blend , from the blender/ folder — in the ollie-3d repository, or on your team's USB stick.
4. Open it, then straight away File ▸ Save As into your own folder, named after your robot ( R3-nova.blend ). Never work in the original.

## 2. What's in the starter file

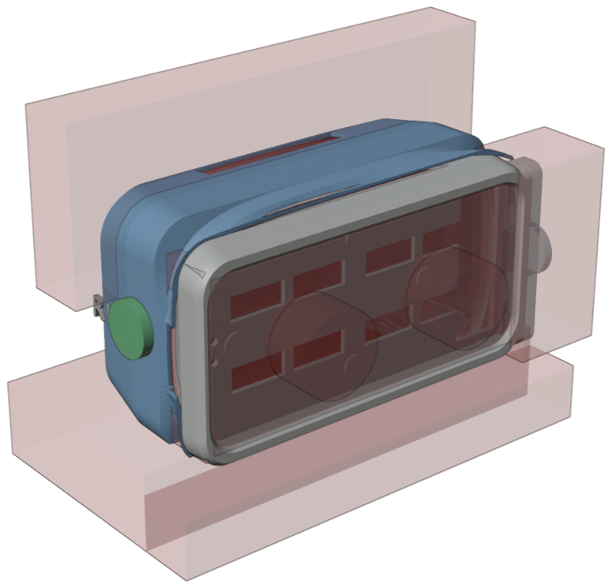
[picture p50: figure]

Colour | What it is | Can you change it?
Blue | The back shell — the part that slides over the back of the head | No — it's locked. You add to it
White | The face plate that holds the phone | No — locked. You can add small details to it
Grey, see-through | Parts inside and underneath: the stock head back, the crown cover, the body, the service cap, the phone | No — they're there so you can see what you're designing around
Red, see-through | Keep-out zones — nothing you make may go in them | No
Green (hidden) | Two examples: an ear disc and an engraved label | Copy them, move them, delete them

The Outliner (top right) has two collections that are yours:

MY ADD-ONS — every object you want to add to the head goes here.
MY CUTS — every object you want to carve out of the head (engraved letters, grooves) goes here.

Anything outside those two collections is ignored when you export. To move an object into one, select it, press M and pick the collection.

Units are millimetres. The face looks toward −Y. Handy views: Numpad 1 front, Ctrl + Numpad 1 back, Numpad 3 side, Numpad 7 top. No numpad? Edit ▸ Preferences ▸ Input ▸ Emulate Numpad, then use the number row.

## 3. The rules

The check script tests all of these for you. Knowing them first saves you redesigns.

Rule | Why
Sink every add-on about 1 mm into the surface. | If it only touches the surface it prints as a separate piece and falls off
Stay out of the red zones. | Each one is something your design would break: the inside of the head, the phone's pocket, the eyes, the phone's glass, the service cap (the phone slides out there to charge), below the head (the neck and body), and the antenna band across the top and back, where the antennae swing
Back shell: 65 g or less in total. The plain shell weighs about 45 g, so you have about 20 g to add. Face plate: 15 g or less added. | Six small motors hold up the head and a 157 g phone. Weight on the head is the one thing they can't argue with
Size: no more than 88 mm out to each side, 75 mm up, 52 mm back, and face details no more than 5 mm proud of the face | Bigger heads hit things when they turn, and cost motor strength
Nothing below the head. | The head nods, tilts and turns right down to the body. The check swings your add-ons through every pose and fails anything that gets closer to the body than the standard head already does
Engravings no deeper than 0.8 mm. | The shell wall is only 1.6 mm thick
Don't cover the phone's camera if your design covers part of the screen. | The camera, near one end of the screen, is how the robot sees who is talking. The check can't see it — hold your print up to the phone and look
Nothing thinner than 1.2 mm. Round every point and edge — at least 1 mm radius on tips. | Thin bits snap. Children will touch this robot
Each add-on and cut is its own closed object. | Open meshes (holes, loose edges) can't be printed. Text objects are fine as they are
Nothing crosses the line where the face meets the back shell. | They are separate prints. A crest that runs from face to crown is two objects, split at that line

## 4. Make an add-on

The example ear disc shows the pattern. Turn on the green EXAMPLES collection (the eye icon in the Outliner) to see it.

1. Add ▸ Mesh ▸ Cylinder (or Cone, UV Sphere, Cube…).
2. Press N for the side panel. Type exact numbers into Location, Rotation, Dimensions.
3. Push it into the surface until about 1 mm is buried. Check it from two views.
4. M ▸ MY ADD-ONS.

Shaping tips:

Round it with a Bevel modifier (width 1–2 mm, segments 3) — modifiers count; the check uses the finished shape.
Smooth it with a Subdivision Surface modifier.

Horns and fins: start from a cone, then Edit Mode (Tab) with proportional editing (O) to curve it. Sculpting is fine on your own objects. Afterwards add a Remesh modifier (Voxel, 0.5 mm) so it is a closed solid.
Mirror left and right with a Mirror modifier (axis X) — both sides for the price of one.
Save weight: hollow a big add-on with a Solidify modifier (thickness 1.6 mm), keeping it closed.

## 5. Engrave something

The example engraved label shows the pattern.

1. Add ▸ Text. Tab to edit it, type your robot's name, Tab again.
2. In the green "a" (Object Data) tab: Geometry ▸ Extrude = 1.0 mm (that makes it 2 mm deep in total), Size = 10–14 mm. Chunky fonts engrave best; letters under 8 mm tall are hard to read.
3. Rotate it so its face points out of the surface, and place it so it cuts 0.8 mm in.
4. M ▸ MY CUTS. The check shows cuts as wireframe so they don't hide what they cut.

Raised letters are the same object put in MY ADD-ONS instead, sunk 0.5–1 mm.

## 6. Check and export

1. Save (Ctrl + S).
2. Click the Scripting tab at the top. reachy_check.py is open in the text editor.

### 3. At the top of the script, set your robot and design name:

ROBOT = "R3"
DESIGN = "nova-horns"
KEEP_ANTENNAE = True # False only if your robot has no antennae
4. Press Run Script (▶, or Alt + P). The report appears in the text editor.

A passing report looks like this:

REACHY HEAD CHECK - R3 / nova-horns (antennae kept)

ADD-ONS
OK | horn_left (shell): closed, attached, clear of every keep-out zone
OK | horn_right (shell): closed, attached, clear of every keep-out zone

CUTS
OK name (shell): closed, attached, clear of every keep-out zone

HEAD MOVEMENT
OK Swept 135 head poses: your add-ons never come closer to the body than the standard head does (nearest 55.5 mm, at pitch +25, roll +20, ...)

WEIGHT
OK back shell: 47.4 g of 65 g
NOTE face plate unchanged - print the standard s10_face_plate.stl

RESULT
PASS - exported:
.../export/R3_nova-horns_shell.stl

PASS means your STL files are in the export folder beside your .blend . FAIL means nothing was exported. Fix each line marked FIX and run it again:

The report says | Do this
reaches inside the head | Pull it outward. Only ~1 mm should be buried
reaches in where the face plate slots into the shell | Move it back from the front edge of the shell by a few mm
covers an eye / would press on the phone's glass | Move it off the eye circles; keep masks in front of the face
blocks the service cap | Keep the service-cap side of the face clear — the side with the small screwed-on cap (+X)
the antennae swing through there | Move it forward or back out of the band across the crown
doesn't touch | Sink it about 1 mm into the surface
isn't a closed solid | Mesh ▸ Clean Up ▸ Fill Holes, or 3D Print Toolbox ▸ Make Manifold
crosses the line where the face plate meets the back shell | Split it into two objects, one each side
comes within … mm of the body | Make the lower part of your design smaller or higher up
… g of 65 g failing | Make add-ons smaller, or hollow them (Solidify)

To look at exactly what will be printed, turn on the RESULT collection in the Outliner. For a last check, select PRINT_shell and run 3D Print Toolbox ▸ Check All — thin walls and steep overhangs show up there.

## 7. Print it

Back shell: collar-down (the open front edge flat on the bed), PETG, 3 walls, 15 % infill, 0.2 mm layers. Tall horns may want a few supports.

Face plate with raised details on the front: print it face up (the flat rear band on the bed), with supports only inside the phone tunnel. The plain face plate prints face down, but raised details would be on the bed. Weigh it on a kitchen scale. The shell must come in at 65 g or less.
Colour: paint with acrylic over a primer, or change filament at a layer height in the slicer (a colour band costs nothing in weight).

The shell slides onto the back of the head and grips by itself. No screws, so you can swap heads in seconds.

## Going further

Want a completely new silhouette, not add-ons on the standard one? The character heads were generated from numbers in Python in the robot's main repository ( hardware/heads/generate_characters.py , specified in hardware/heads/CHARACTER_SPEC.md ), so the fit to the robot is exact. Describe your shape to your mentor. The mentor can also make a starter file from any of the character shells:

blender -b --factory-startup -P hardware/heads/blender/make_starter.py -- \
--shell character_pip_shell --out pip_starter.blend

AP P E N D IX A

# Appendix A — Shopping list

Everything to buy. What to print is Stage 1. Quantities are per robot, with a ×6 column for the whole program. Prices change; confirm each listing before ordering.

## Motors — the expensive part

Part | Per robot | ×6 | Fleet spares | Notes
DYNAMIXEL XL330-M288-T | 14 | 84 | 6 | 6 for the head, 4 for each arm. One of the original robot's motors arrived with a mis-moulded gear — buy spares
DYNAMIXEL XL330-M077-T | 2 | 12 | 1 | The antennae — a weaker, faster version. Don't mix them up with the M288
DYNAMIXEL XC330-M288-T | 1 | 6 | 1 | The body turn. Metal case, because it turns the whole robot

All three are 5 V motors on the same 3-pin cable. Each motor comes with one short cable.

## Motor bus and power

Part | Per robot | ×6 | Notes
ROBOTIS U2D2 | 1 | 6 | The USB adapter between the Pi and the motors
ROBOTIS U2D2 Power Hub Board Set | 1 | 6 | Where the motors plug in and get their 5 V
ROBOTIS Robot Cable-X3P, assorted lengths | 8 | 48 | Longer motor cables for the arms and the run up through the body — the stock ones are short
12 V power brick, 120 W or more | 1 | 6 | The robot's one plug for the motors and the phone. Ollie's is 160 W
12 V → 5 V step-down converter, 10 A (50 W) | 1 | 6 | Feeds the Power Hub, i.e. all 17 motors. ⚠️ The motors must only ever see 5 V
12 V → 5 V USB charger module (USB-A) | 1 | 6 | Charges the phone in the head
Fuse holder + 10 A fuses, rocker switch, wire, lever connectors, 2200 µF capacitor | 1 set | 6 | The mentor builds the power wiring from these — see Appendix B

## Brain — and the workbench

Part | Per robot | ×6 | Notes
Raspberry Pi 5, 4 GB | 1 | 6 | Ollie runs on a 2 GB board and it is a real ceiling. 4 GB removes that
Official Raspberry Pi 27 W USB-C power supply | 1 | 6 | Not a generic 5 V supply — one measured 4.99 V on Ollie and made the Pi crash
microSD, 32 GB, high-endurance (Samsung PRO Endurance or SanDisk Max Endurance) | 1 | 6 | +2 spares. Label it with the robot number
Raspberry Pi 5 Active Cooler | 1 | 6
USB stick, 16 GB or more | 1 | 6 | The student kit, and the robot's calibration backups
Monitor with HDMI, USB keyboard and mouse | 1 set | 6 | The Pi is the workbench computer from Stage 2 on. Any school monitor and keyboard will do; they can be shared once a robot is finished
Micro-HDMI to HDMI cable | 1 | 6 | The Pi 5's video ports are micro-HDMI

## Face

Part | Per robot | ×6 | Notes
Samsung Galaxy S10 (SM-G973), used is fine | 1 | 6 | The plain S10 — not the S10e, S10+ or S10 5G. The face plate is sized to this phone to a fraction of a millimetre. Check the screen has no burn-in and the battery isn't swollen. A different phone means a new face plate (Stage 6)
USB-A to USB-C cable, about 1 m, thin | 1 | 6 | From the USB charger in the base, up through the body, to the phone

## Base and yaw joint

Part | Per robot | ×6 | Notes
6816-2RS thin-section bearing, 80 × 100 × 10 mm | 1 | 6 | +1 spare
Brass spacer, ⌀6 mm OD × ⌀3.2 mm bore × 20 mm | 4 | 24 | R1 measures one of the body's four ⌀6.64 columns with a pin gauge before the fleet order
Stick-on rubber feet, ⌀12 mm | 8 | 48 | 4 for the plinth, 4 for the Pi case

## Antenna wire

Part | Per robot | ×6 | Notes
Stiff wire, brass or steel | about 50 cm | 3 m | Bent by hand into the two antennae. R1 measures the hole in the printed antenna hub and buys wire that's a snug push fit

## Arms (both arms)

Part | Per robot | ×6 | Notes
GT2 closed-loop belt, 122 mm (61 teeth), 6 mm wide | 4 | 24 | Shoulder pitch and shoulder roll, both arms. +1 spare per robot
GT2 closed-loop belt, 140 mm (70 teeth), 6 mm wide | 2 | 12 | The elbows. +1 spare per robot

## Screws

The stock Reachy parts use the screws listed in the official Reachy Mini assembly guide. (https://huggingface.co/spaces/pollen-robotics/Reachy_Mini_Assembly_Guide) Buy each team an M2 / M2.5 / M3 assortment (machine screws, self-tapping screws and nuts) for those. The custom parts need these specifically.

Head, face and base

Screw | Per robot | Where
M2 × 5 self-tapping | 24 | Motor arms → motor boss (4 per arm)
M3 × 18 + M3 nut | 12 + 12 | Rods: through the ball into the motor arm, and the rod tops into the neck plate. R1 confirms the top-end length
M2 × 10–12 self-tapping | 2 | Face service cap
M2 × 8 | 4 | Yaw motor → the base's motor bridge
M2 × 10 | 4 | Yaw clamp → the yaw motor's boss
M3 × 8 countersunk | 3 | Yaw clamp → rotor, from below
M3 × 14 thread-forming | 6 | Base cap → plinth, sideways through the drum wall
Body clamshell screws, longer than stock | 4 They now reach through the rotor into the body. R1 measures the length
M3 × 8–10 | 4 | U2D2 Power Hub Board → its tray
M2.5 × 8 | 8 | Pi → tray (4), cover → tray (4)
M3 × 16 thread-forming | 4 | Pi case → plinth wall

Arms — for both arms

Screw | Per robot | Where
M2 × 5 countersunk (90°, DIN 965) | 32 Boss adapters (4 each × 6) and hand adapters (4 each × 2). Countersunk, not pan | head: the seat is a cone
M2 × 8 | 6 | The centre screw in each small pulley
M2 × 16 | 18 | Big pulleys → their joints, 3 each
M2 × 16 countersunk | 4 | One per belt cover. Not shorter — the screw crosses the cover's own boss first
M2 × 6 | 8 | Pitch and elbow motors, 2 each
M2 washer, about 5 mm across | 4 | Under the elbow motors' screws
M2 × 20 self-tapping | 4 | Roll motors, 2 each
M3 × 12 | 4 | Wrist clamps, 2 each
M3 × 10 self-tapping, or a 2.5 mm pin | 2 Pins each pitch shaft to its fork
M3 × 12 + M3 nut | 8 + 8 | Shoulder housings → body shell, 4 each. R1 confirms the length

## Tools

Per team: metric hex keys and small screwdrivers (Phillips #0 and #1, and a small flat blade for belt tension), digital calipers, a multimeter, a drill with 2.5 mm and 3.2 mm bits, a small vice (for pressing bushings), a small spirit level (or a phone level app), flush cutters, needle-nose pliers, a file, zip ties, painter's tape and a marker, a hot-glue gun, a deburring tool and fine sandpaper.

Shared: a kettle and a thermometer (ball joints are swaged in 80–90 °C water), a pin gauge set or drill bits to measure holes, and a Meta Quest headset for the VR test in Stage 5.

AP P E N D IX B

# Appendix B — Mentor notes

This appendix is for the adults. It covers what has to be ready before the students start, and the parts of the build that can break hardware if they're done in the wrong order.

## Before day one

### 1. The student kit — one USB stick per team

On a computer with the robot's main repository ( redarchlabs/reachy-the-robot ):

.venv-cad/bin/python docs/student-build/make_pdf.py
.venv-cad/bin/python scripts/make_student_kit.py

That writes dist/reachy-student-kit/ (and a zip of it). Copy the folder onto six USB sticks labelled R1–R6. The kit holds the print files (all millimetres), this book, the Blender starter, and software/reachy-software.tar.gz : the robot software as committed, plus the 3D models and browser libraries (Blockly, three.js) its pages need. It deliberately holds no .env , no calibration and no voice models — a student robot starts clean.

The same print files, this book's chapters and the Blender starter are published to the ollie-3d repository,
without the software: .venv-cad/bin/python scripts/export_ollie3d.py <your ollie-3d checkout> , then
commit and push there.

### 2. The SD cards

Raspberry Pi Imager → Raspberry Pi 5 → Raspberry Pi OS (64-bit), the version with the desktop. In the Imager's settings:

hostname reachy-r1 … reachy-r6 ;
a username and password — write them down; the install in Stage 2 asks for the password;
the wifi the robots will use, and your country, time zone and keyboard;
SSH, if you want to reach the Pis from a laptop (optional — nothing in the book needs it).

Label each card with its robot number.

### 3. The network

Two things are needed from the wifi, and school networks often give only the first:

1. Internet, for the install in Stage 2 (system packages and Python packages).
2. Devices that can reach each other. The phone in the head, the Pi and (for the VR test) the headset all talk to each other directly. Many school networks block that ("client isolation"), and it shows up as a phone that simply can't open the robot's page. If so, bring a travel router and put the robots on its wifi.

Reserve each Pi's address in the router (a DHCP reservation) so it never changes — the phone's home-screen icon has the address in it.

### 4. Don't deploy student robots from Ollie's working copy

scripts/deploy_pi.sh was written for Ollie. On any Pi that doesn't have them yet, it seeds two files from the working copy it runs in: Ollie's .env (with its credentials) and Ollie's data/motor_calibration.json — motor positions measured on a different head, which can drive a student head against its own rods and break a printed rod or motor arm. Student robots are installed from the kit, on the Pi, as Stage 2 describes. If you ever do use deploy_pi.sh for a student Pi, run it from a fresh clone, which has neither file.
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
